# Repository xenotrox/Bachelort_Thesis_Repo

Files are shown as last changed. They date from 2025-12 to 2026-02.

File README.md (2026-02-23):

# Real-Time sEMG Control of a Bionic Hand (Bachelor Thesis)

This repository contains the complete hardware, firmware, and software implementation for a surface Electromyography (sEMG) controlled bionic hand. The project serves as a functioning prototype developed for a Bachelor Thesis, focusing on real-time signal processing, feature extraction, and motor control.

The physical hand is based on a remixed version of the open-source **InMoov** robotic hand, optimized for reliability and educational demonstration.

## 📂 Repository Structure

The project is divided into four main directories, each containing its own specific documentation:

- **`/doc`**: Contains the final academic thesis (`Bachelorarbeit-1.pdf`) and the presentation slides used for the defense.
- **`/firmware`**: Contains the C++ code for the microcontroller (Arduino). It handles the real-time acquisition of analog sEMG signals (sampled at 1000 Hz), applies digital Butterworth bandpass filters, calculates muscle activation thresholds (Waveform Length), and actuates the servos safely.
- **`/hardware`**: Contains all 3D printing files (STLs and CAD). This includes the original and remixed InMoov hand parts (reinforced forearm with 5 mm bolt holes, upgraded servo pulleys, teflon tube guides) as well as the custom-designed display stand and electronics housing.
- **`/software`**: Contains the data science and analysis pipeline. Includes Jupyter Notebooks and Python modules used for evaluating raw signal noise, comparing filter performances (4th vs. 6th-order), extracting features, and training the activation thresholds used by the firmware.

## 🚀 Getting Started

To replicate or understand this project, it is recommended to explore the sub-modules in the following order:

1. **Hardware Assembly**: See `/hardware` to print the PLA components and assemble the tendon-driven hand.
2. **Data Analysis**: Navigate to `/software` to see how raw sEMG signals were analyzed and how the filter coefficients and muscle activation thresholds were calculated.
3. **Microcontroller Setup**: Go to `/firmware` to flash the main control code onto the Arduino and start reading real-time muscle inputs.

## 🛠️ Key Technologies & Requirements
- **Microcontroller:** Arduino Uno (or compatible)
- **Programming Languages:** C++ (Firmware), Python 3.x (Software Analysis)
- **Data Analysis Libraries:** `numpy`, `pandas`, `scipy`, `matplotlib`, `jupyter`
- **3D Printing:** FDM Printer, PLA Filament

## 📜 Credits
The physical hand design is heavily based on the [InMoov open-source 3D printable robot](https://inmoov.fr/) created by Gael Langevin, utilizing remixes specifically tailored for improved tendon tension and forearm strength.

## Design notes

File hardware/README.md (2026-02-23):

# Hardware

This directory contains all the 3D models and CAD files needed to physically build the bionic hand and its display stand.

## Structure
- **InMoov/**: Contains the files for the robotic hand.
  - **Original/**: Unmodified STL files directly from the open-source InMoov project (Fingers, Forearm, RightHand, RotationWrist).
  - **Remix/**: Modified parts customized for this project, including a reinforced forearm with 5 mm bolt holes and updated servo pulleys for the tendon system.
- **Custom Stand/**: Original CAD designs for the educational display stand, including the Arduino holder, bottom box and top box.
- **Printer Calibration/**: Small test STLs used to dial in the 3D printer's Z-offset and dimensional accuracy before printing the final parts.

## Printing Notes
All parts are designed to be printed in PLA. Please refer to the specific README files in the subdirectories (e.g., `InMoov/Remix/Forearm/README.txt`) for specific infill and speed recommendations.

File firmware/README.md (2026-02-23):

# Firmware

This directory contains all Arduino C++ code and related scripts required to operate the bionic hand prototype. 

## Structure
- **Hand_Control/**: The main production code for the Arduino Uno. It processes analog sEMG signals using a 6th-order Butterworth bandpass filter, calculates the Waveform Length (WL), and actuates the servo motors based on trained thresholds. It also includes `serial_plotter.py` for real-time visualization on a connected PC.
- **tests/**: A collection of isolated Arduino sketches used during development to verify individual components. Includes tests for LEDs, potentiometers, servo limits (`Hand_Test`), filter performance, and sensor connectivity.

## Setup
Upload the `Hand_Control.ino` sketch to your Arduino Uno using the Arduino IDE. Ensure the custom C++ filter libraries (`BandpassFilter6thOrder.h`/`.cpp`) are in the same directory.

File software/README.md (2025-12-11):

# Analysis & Control Software

This directory contains the Python code and Jupyter Notebooks used for processing sEMG signals, training threshold models, and evaluating filter performance for the Bachelor Thesis.

## 📦 Prerequisites

This project requires **Python 3.x** and the following scientific libraries. You can install them via pip:

```bash
pip install numpy pandas scipy matplotlib jupyter
```
Note: If you wish to generate production-ready plots with LaTeX formatting, ensure you have a local LaTeX distribution installed (e.g., TeX Live or MiKTeX) and set ENABLE_LATEX = True in src/config.py.

## 📂 Directory Structure

- notebooks/: The main entry points for analysis. These are numbered to indicate the recommended execution order.
- src/: Helper modules containing the core logic (filters, feature calculation, data loading).
  - config.py: Global settings (sampling rate, constants, plotting options).
  - filters.py: Implementation of Notch and Butterworth filters.
  - features.py: Signal feature extractors (RMS, Variance, Waveform Length).
  - data_loader.py: Utilities for loading raw ADC text files and labeled CSVs.
- data/: Place your raw signal files (.txt) and labeled training data (.csv) here.
- results/: Generated plots, trained threshold values, and filter coefficients are saved here automatically.

## 🚀 Usage Guide

It is recommended to run the notebooks in the following order to replicate the full analysis pipeline:
### 1. Raw Signal Analysis

- File: 01_Raw_Signal_Analysis.ipynb
- Goal: Visual inspection of the raw sEMG signal directly from the ADC.
- Key Output: Plots showing the DC offset (approx. 1.5V) and baseline noise.

### 2. Filter Evaluation

- File: 02_Filter_Evaluation.ipynb
- Goal: Compare the "Original Filter" (Notch + Simple High/Low pass) against 4th and 6th Order Butterworth designs.
- Key Output: Power Spectral Density (PSD) plots and signal-to-noise comparisons to justify the final filter choice.

### 3. Model Training

- File: 03_Model_Training_Evaluation.ipynb
- Goal: Load labeled training sequences to determine optimal thresholds for muscle activation.
- Key Output: Generates trained_thresholds.csv in the results folder.

### 4. Feature Evaluation

- File: 04_Feature_Evaluation.ipynb
- Goal: Compare different feature extraction methods (RMS vs. Variance vs. Waveform Length) for responsiveness and stability.

### 5. Real-Time Control Simulation

- File: 05_RealTime_Control.ipynb
- Goal: Simulates the final control logic using the selected filter and trained thresholds on test data.
    
## ⚙️ Configuration

You can adjust global settings in src/config.py:
- SAVE_PLOTS: Set to True to save figures to results/drafts or results/figures.
- ENABLE_LATEX: Set to True to use LaTeX fonts for plots (requires LaTeX installation).
- FS: Sampling frequency (Default: 1000 Hz).
- V_REF: ADC Reference Voltage (Default: 5.0 V).

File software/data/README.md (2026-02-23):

# Software Data

This directory stores the raw and processed datasets used by the Jupyter notebooks.

- **raw_signal.txt / realtime_stream.txt**: Unprocessed ADC serial dumps directly from the Arduino.
- **labeled_training_data/**: Contains sequence CSVs (`train_seq_01.csv` to `train_seq_10.csv`) used to train the activation threshold models. These files include the filtered signal and a binary label indicating muscle contraction.
- **test_data/**: Contains diverse validation sets (e.g., fatigue tests, sudden dropouts, quick pulses) to evaluate the system's robustness in real-world scenarios.

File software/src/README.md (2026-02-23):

# Source Code (src)

This directory contains the core Python modules used by the Jupyter Notebooks for analysis.

- **config.py**: Global configuration variables (e.g., 1000 Hz sampling rate, ADC voltage, plotting preferences).
- **data_loader.py**: Functions to parse raw `.txt` serial logs and labeled `.csv` training data into Pandas DataFrames.
- **features.py**: Implementations of feature extraction algorithms (Waveform Length, Root Mean Square, Variance).
- **filters.py**: Signal processing functions, including Notch filters for powerline noise and digital Butterworth bandpass filters.
- **visualization.py**: Helper functions for generating standardized matplotlib graphs.

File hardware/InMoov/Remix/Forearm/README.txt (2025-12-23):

Inmoov Forearms Modded by Mindless on Thingiverse: https://www.thingiverse.com/thing:1927150

Summary:
Many Thanks to -Mr Gael- "Inmoov" DesignerForearm’s- Part-A -Part-B-“ Plus” Upper and Lower WristThis Mod joins the Four smaller sections into Two-,, the forearms total height is just under 200mm high,,, so make sure you can print this high before starting !!,I have included the small section pieces if you can’t print that high, the bolthole has been reduced to 5mm to increase strength- the pictures give you all the information youneed there is no change to the actual design except for the 5mm bolt hole, and 2.2mm extension toreduce the angle and add a bit more strength,, all pieces where hand joined and are error free-the Bicep servo mount has been modded to have a 5mm hole to match the forearms- Slow down the printing speed due the small Footprint and because how tall it is, but also because itIs a thin object the infill will have short rapid movement this will make the object become unstuck ifthey became too violent so set infill speed to- 60mm/sec- and tick the box that allows-“collapse thin lines into single trace  which is “on”  by default in Sli3er,- there’s a good chance you will get the “Death Shakes” if  this is turned off and the infill speed is higher than 60mm/sec-  there is a speed setting in Slic3r that is meant to deal with this problem but it’s a “Hit or Miss” when an object is sliced up- I’ve learnt not to Trust it…My Forearms where printed using PLA- ED3v6-- 0.4mm NozzleLayer Hight -0.3mmLayer Default Width-0.5Perimeters -2 - both@ 40mm/sec-Infill- 100% @ 60mm/secBrim- 15 Loops- 3-Layers highReducing the printing speed on some object makes only a small difference on printing time, same as using 100% infill- it will only use a few extra meters of filament- this is one of them Objects, it’s worth taking the time to do right-The" Upper" and" Lower"- Wrists (pic-9) have had the walls thickened In certain sections due to bleeding in the walls at some spots (Horizontal Scarring ) this was probably a result of my printing setting and not a fault of the part- but the part is a lot stronger now and still compatible with everything else,,,Parts fit together beautifully and very little clean-up is requiredif you your printing the x4 Short pieces with the 5mm Elbow holes you have to go to the inmoov website to get the -Top Sections- all the parts are backwards Compatible--SketchUp Files are included with the Download for you to mod --=Mindless=-*Note- 2--One picture shows all the Mods available in my collection but only the Forearms are includedin this download

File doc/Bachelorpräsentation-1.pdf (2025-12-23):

# Real-Time sEMG Control of a Bionic Hand for Educational Demonstration

## Lukas Zach

Bachelor Thesis Presentation TU Graz, Institute of Biomedical Imaging 01.12.2025

# Motivation ²

Introduction

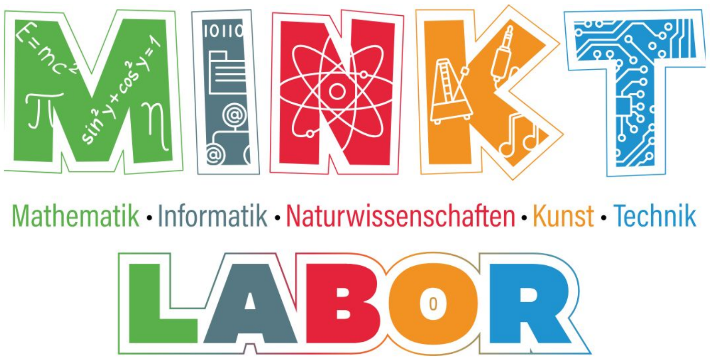
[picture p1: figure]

Image: Super Science Team, TU Graz

# Motivation ²

Introduction

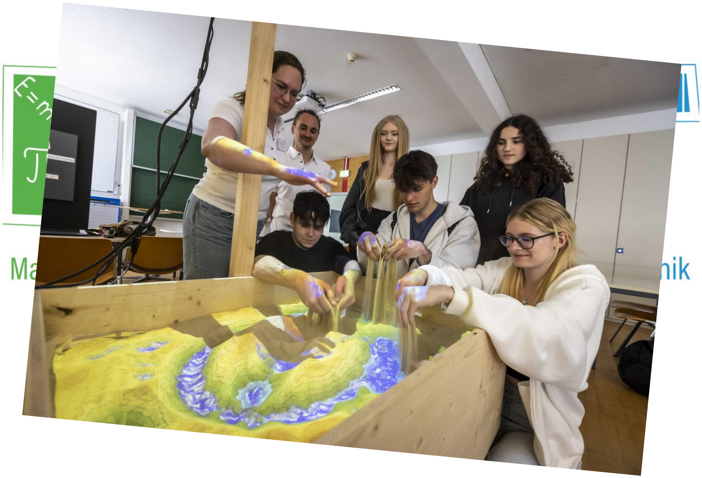
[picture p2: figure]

Image: Super Science Team, TU Graz

# Motivation ²

Introduction

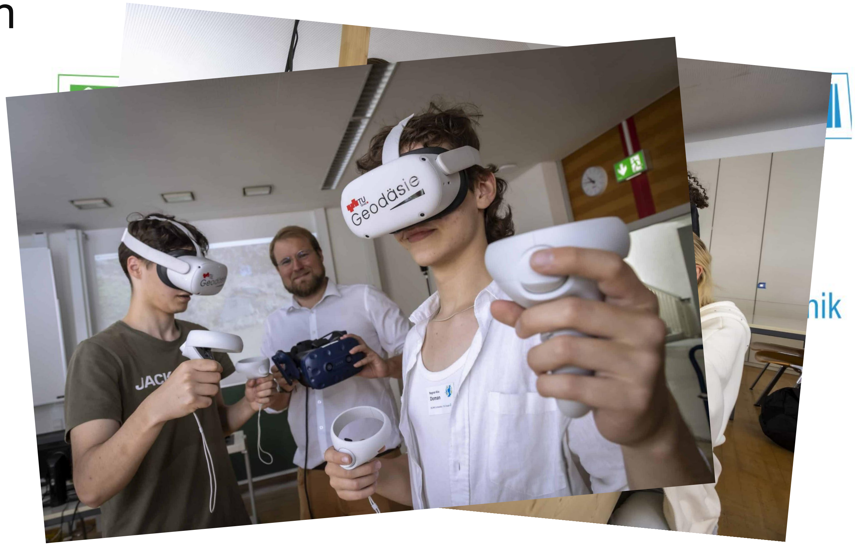
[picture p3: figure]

Image: Lunghammer, TU Graz

# Motivation ²

Introduction

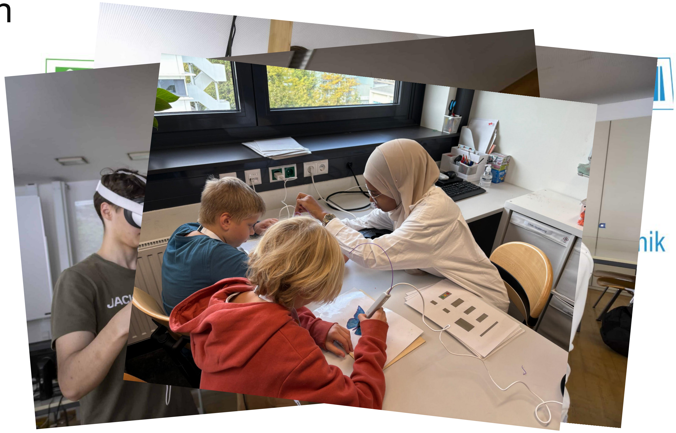
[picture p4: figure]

Image: Nina Botthof, TU Graz

# Motivation ²

Introduction

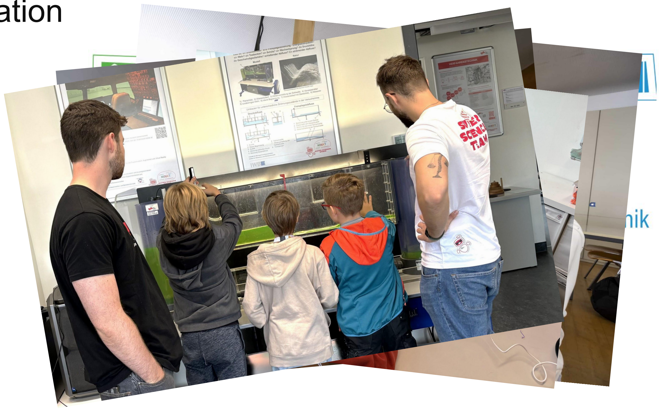
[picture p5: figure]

Image: Nina Botthof, TU Graz

# Motivation ²

Introduction

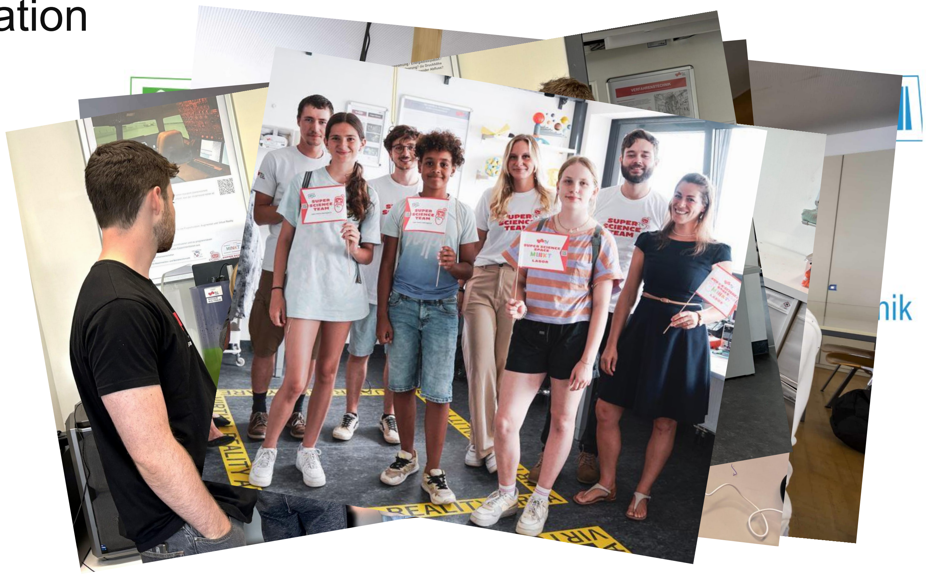
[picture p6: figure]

Image: Science Garden

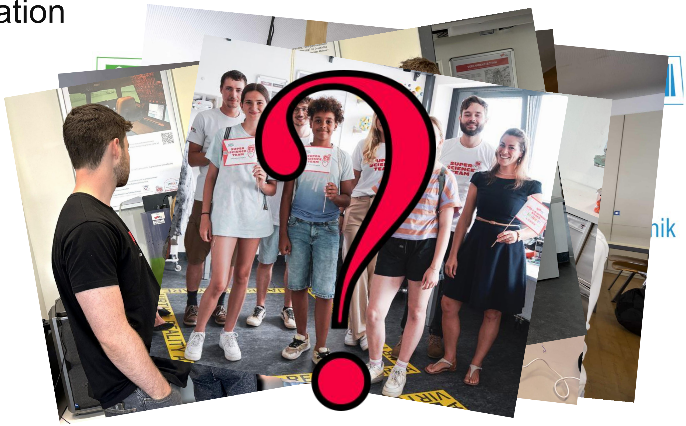
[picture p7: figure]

# Motivation ²

Introduction

# Goal ³

Introduction

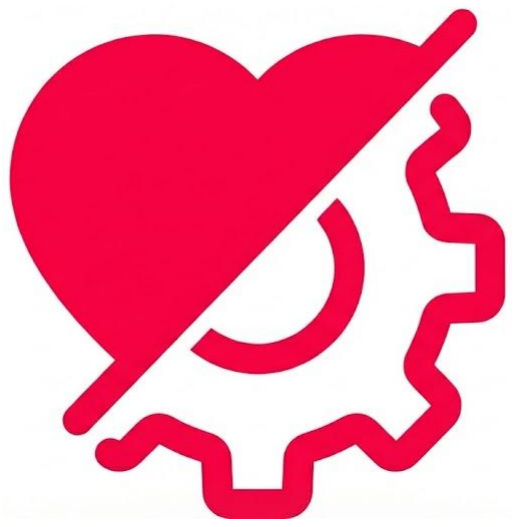
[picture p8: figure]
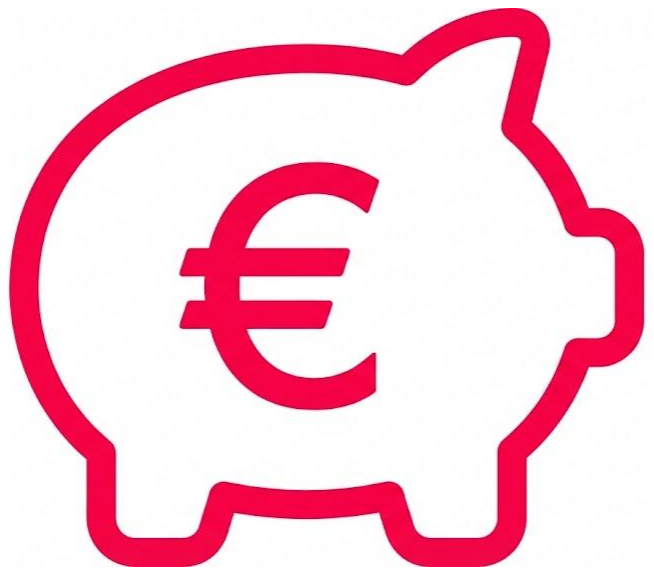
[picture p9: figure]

# Low budget

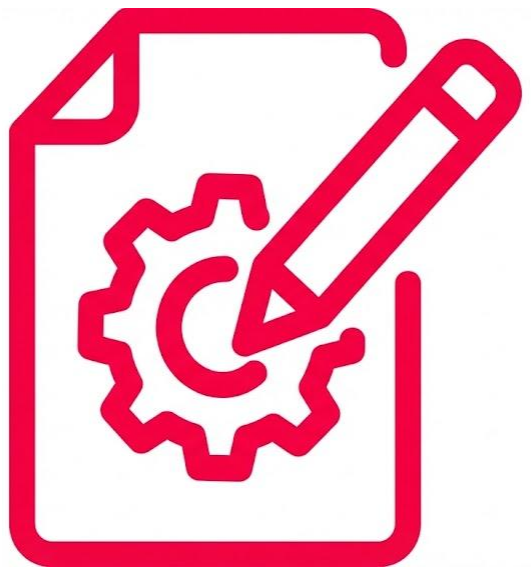
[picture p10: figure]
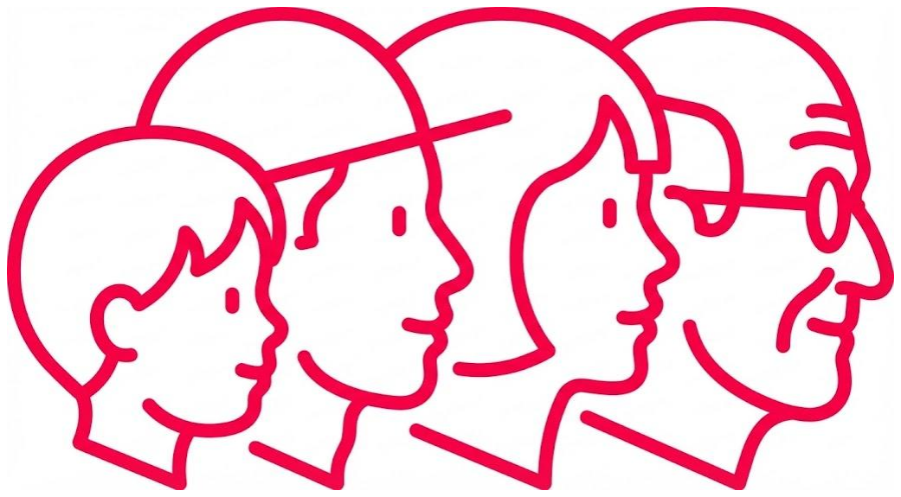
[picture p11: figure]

# Functioning Prototype

# Representative

# For all age Groups

Method

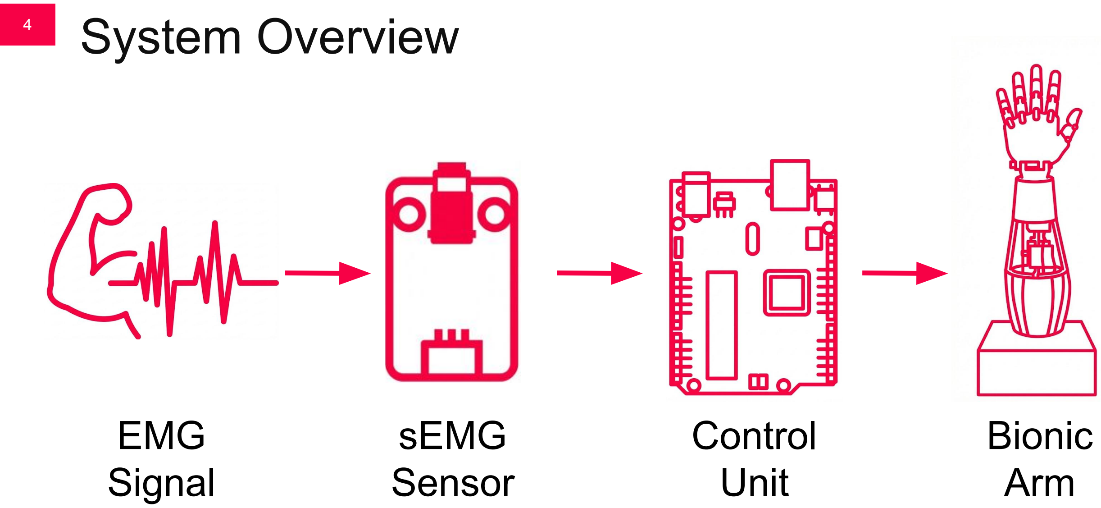
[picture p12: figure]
System Overview ⁴; EMG Signal; sEMG Sensor; Control Unit; Bionic Arm

# sEMG Signal ⁵

Method

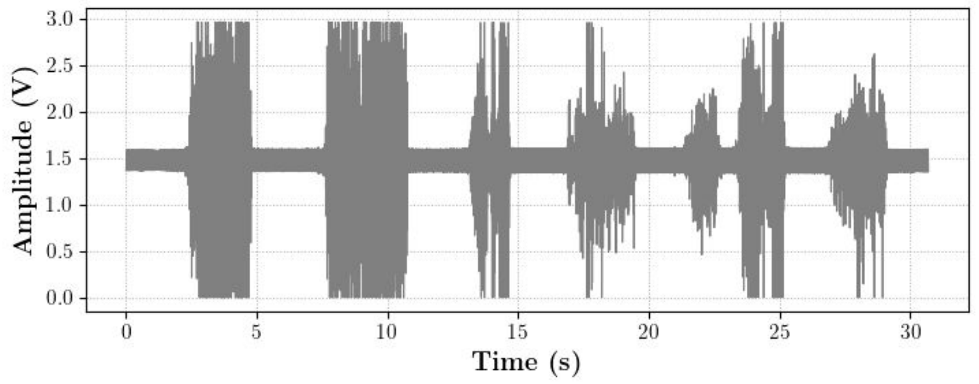
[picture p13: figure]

Image: Lukas Zach

# Gravity: Analog sEMG Sensor ⁶

Method

- Type: Dry Electrode Sensor.

## - Why: No conductive gel required (ideal

for high-traffic lab use).

## - Configuration: Differential amplification

(rejects common noise).

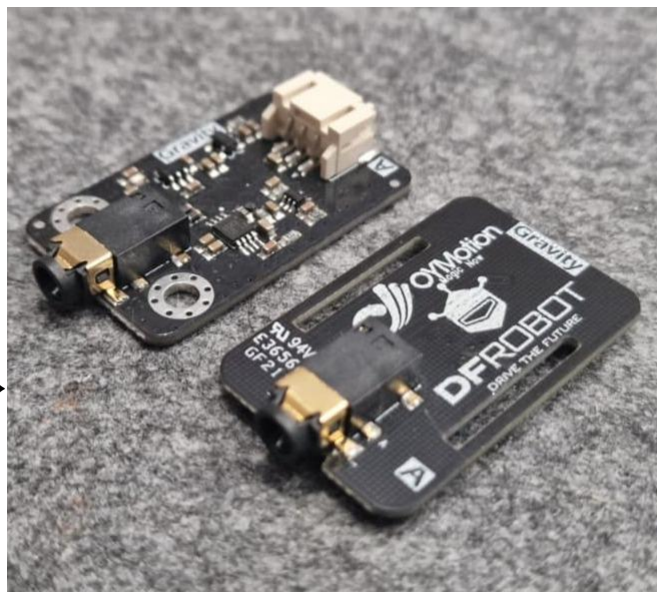
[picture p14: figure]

## - Output: Amplified analog signal (0–3V) →

Read by Arduino.

Image: Lukas Zach

# Control Unit ⁷

Method

### - Processor: Arduino Uno Rev3 (Sampling at

1000 Hz).

### - Interface: Sensor Shield V5.0 for easy

component connection.
- Power Logic: Isolated Power Supply.
- Arduino powered via USB.
- Servos powered by external 15A supply.

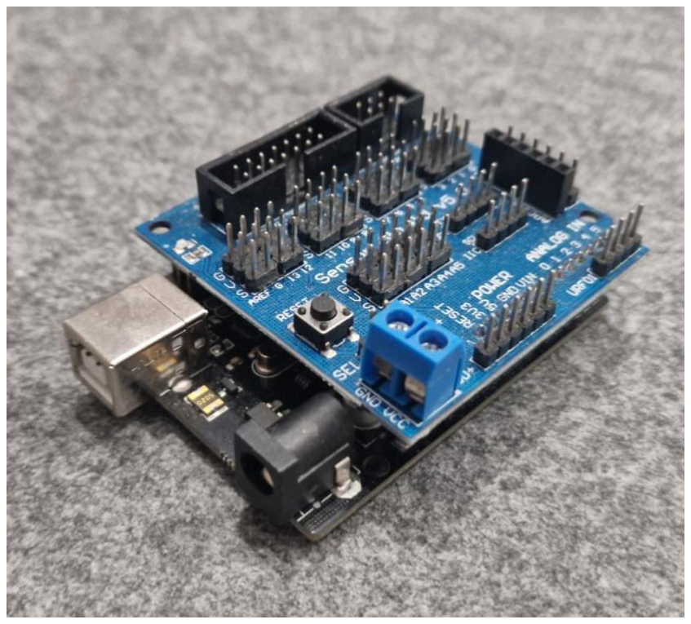
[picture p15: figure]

Image: Lukas Zach

# InMoov Bionic Arm ⁸

Method

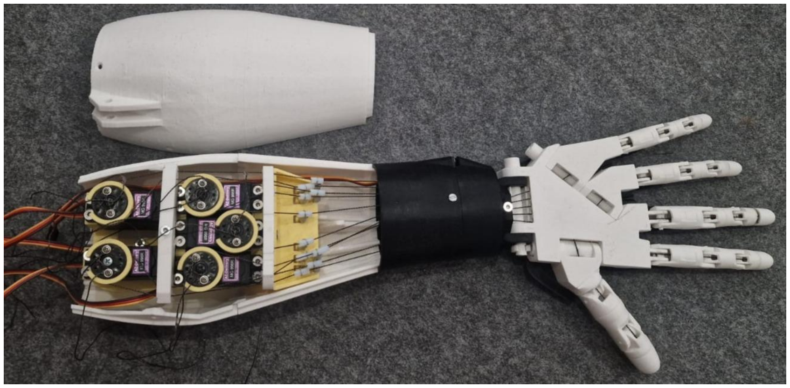
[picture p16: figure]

Image: Lukas Zach

# Mechanical Implementation ⁹

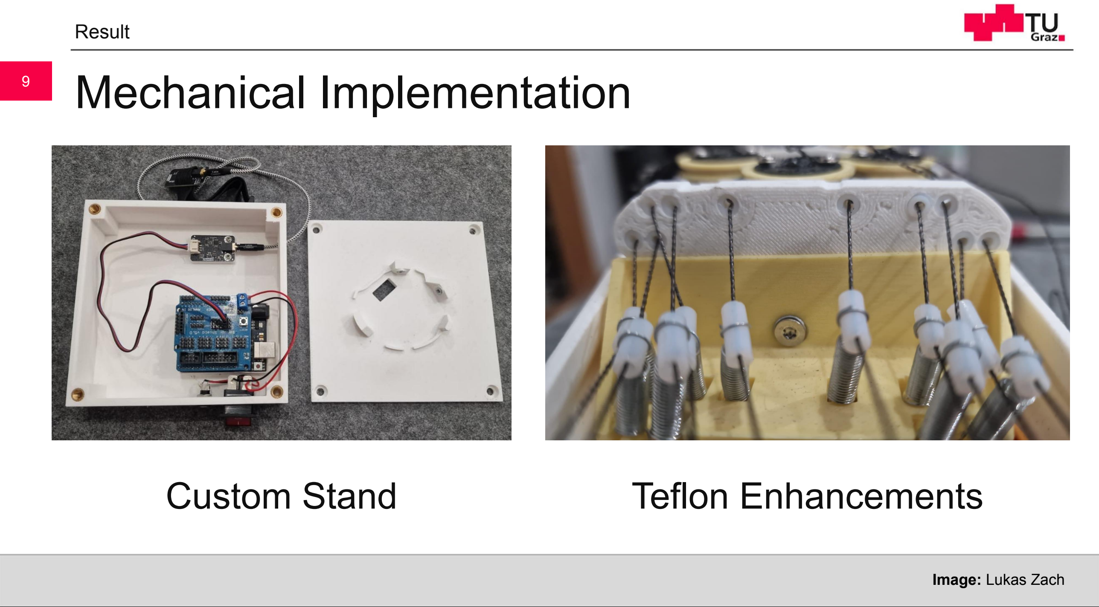
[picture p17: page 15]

Result

Custom Stand | Teflon Enhancements

Image: Lukas Zach

# Signal Processing: Filter Design ¹⁰

Result

Image: Lukas Zach

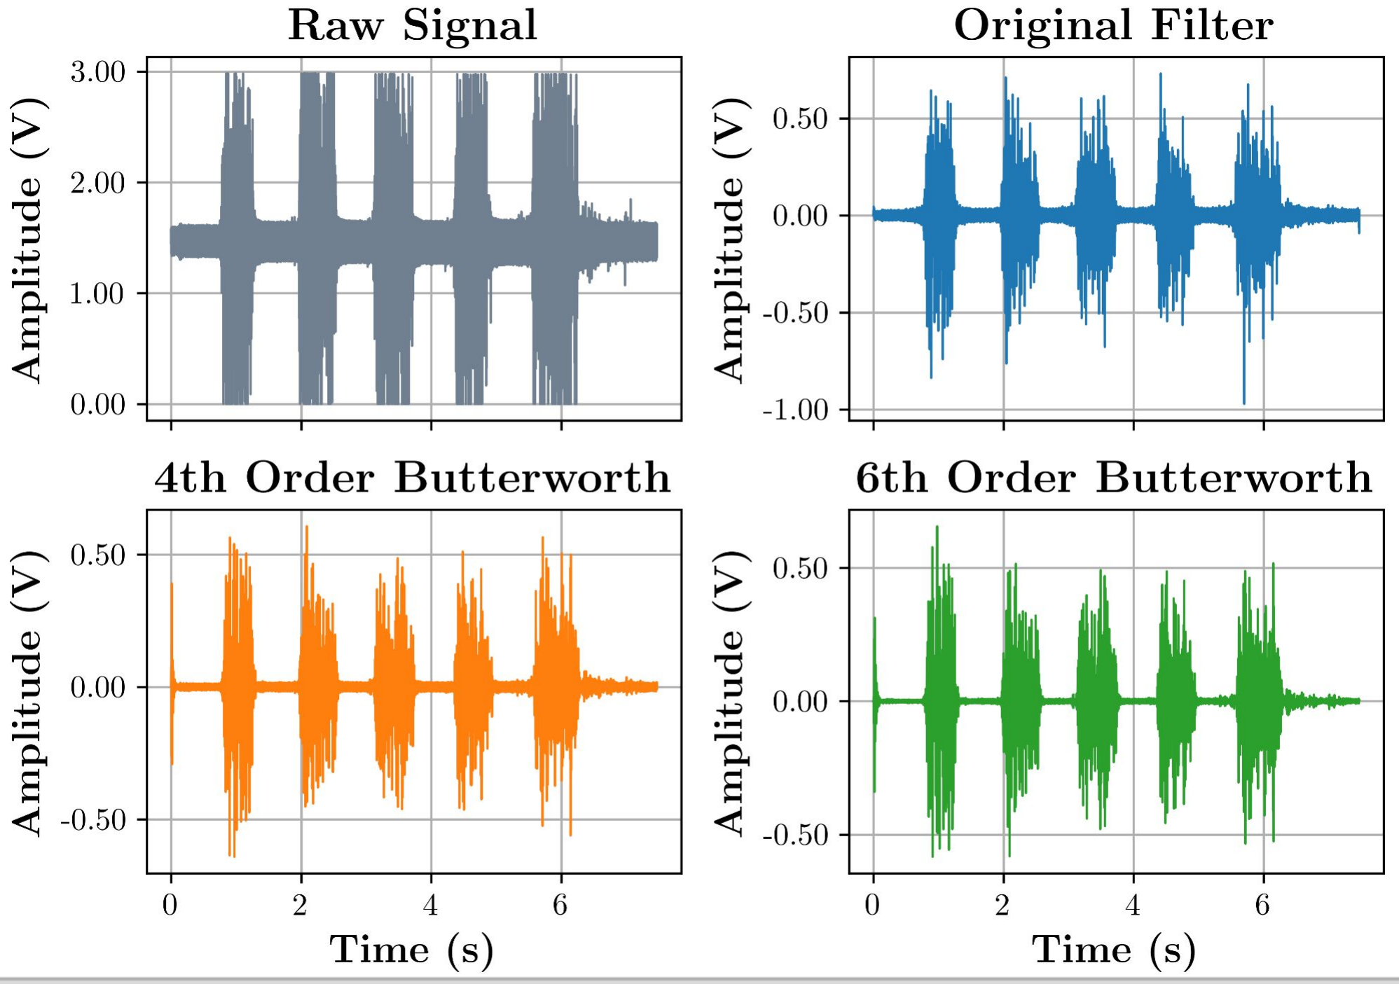
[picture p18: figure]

# Signal Processing: Filter Design ¹¹

Result

Image: Lukas Zach

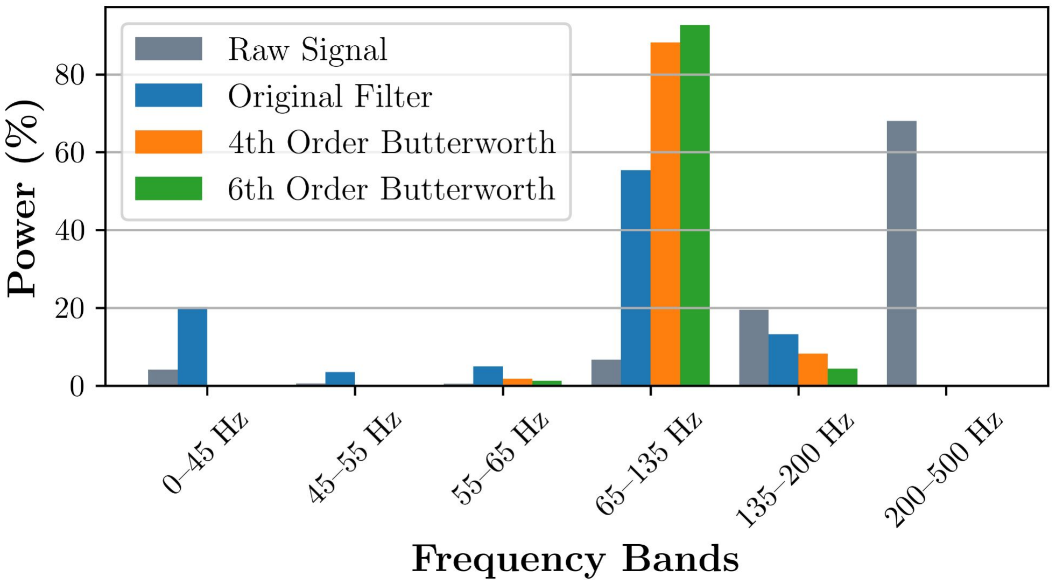
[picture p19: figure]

# Signal Processing: Feature Extraction ¹²

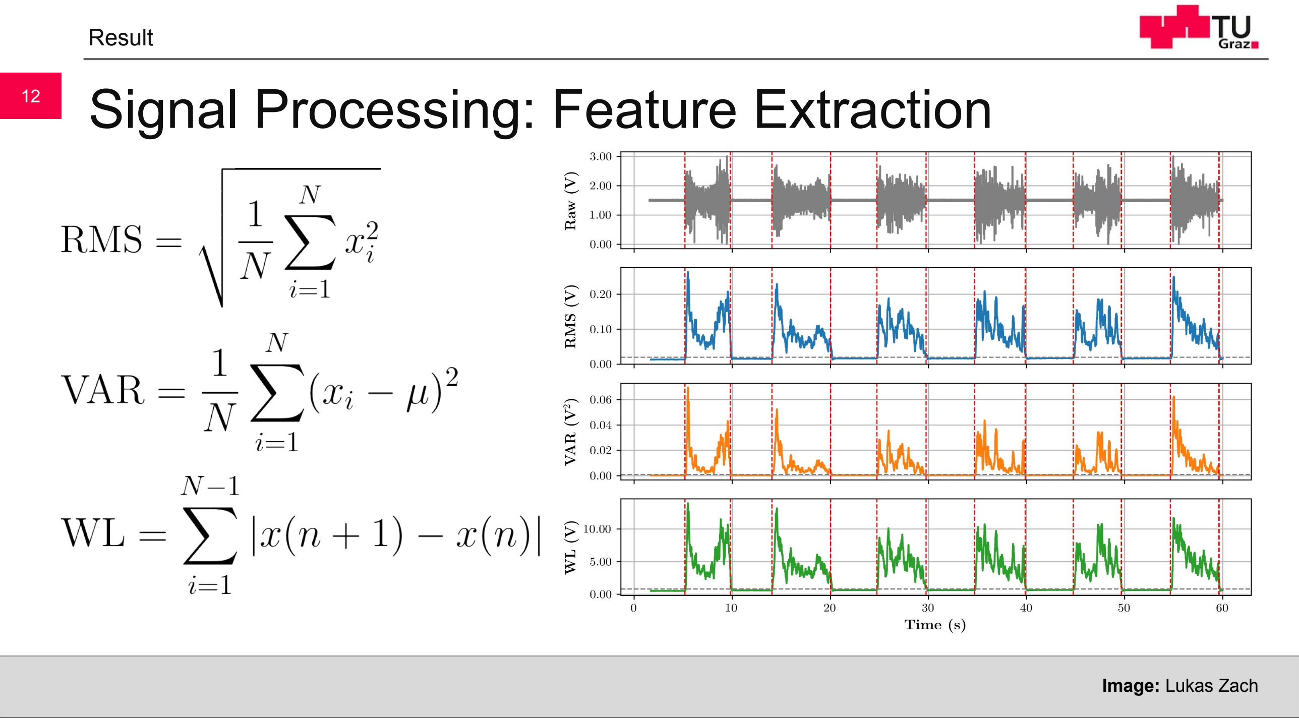
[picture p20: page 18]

Result

Image: Lukas Zach

# Signal Processing: Accuracy & Delay ¹³

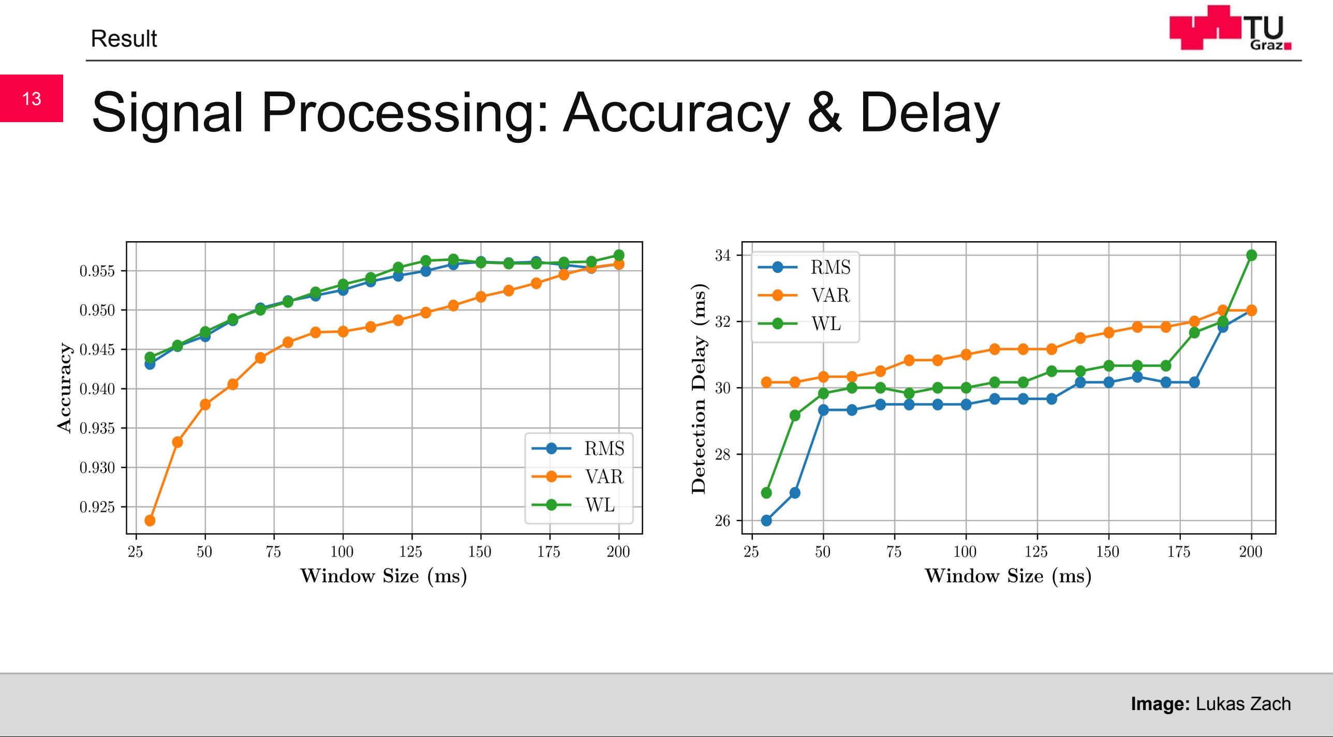
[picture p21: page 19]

Result

Image: Lukas Zach

# Discussion & Limitations ¹⁴

Result

## Signal Stability

- Issue: Sensor detachment creates massive noise
spikes.
- Impact: False positives
(unintended closing).
- Status: Software "Guard" added, but hardware
connection needs
improvement.

## Mechanical Wear

- Issue: Tendons (fishing line) stretch over time.
- Impact: Incomplete finger extension.
- Status: Teflon tubes
reduced friction, but regular re-tensioning is still
required.

## Usability & Scope

- Issue: Manual threshold
turning needed per user.
- Impact: Validated on N=4 subjects.
- Status: Auto-calibration required for unsupervised
public use.

# Conclusion ¹⁵

Result

# Achievements

✔ Functional Prototype:

Successfully integrated InMoov hand with custom sEMG control.

✔ Safety First:

Implemented dual-threshold "Disconnection Guard" to prevent erratic movement.

✔ Cost-Effective:

Created a repairable, modular system suitable for the MINKT Lab.

# Futur Work

→ Auto-Calibration:

Find a algorithm to adjust the thresholds automatically.

→ Long-Term Durability:

Conduct longer stress tests on the system and improve the tensioning system.

→ Hybrid Features:

Investigate combining RMS and Waveform Length or other features.

Image: Icons generated using Google Gemini.

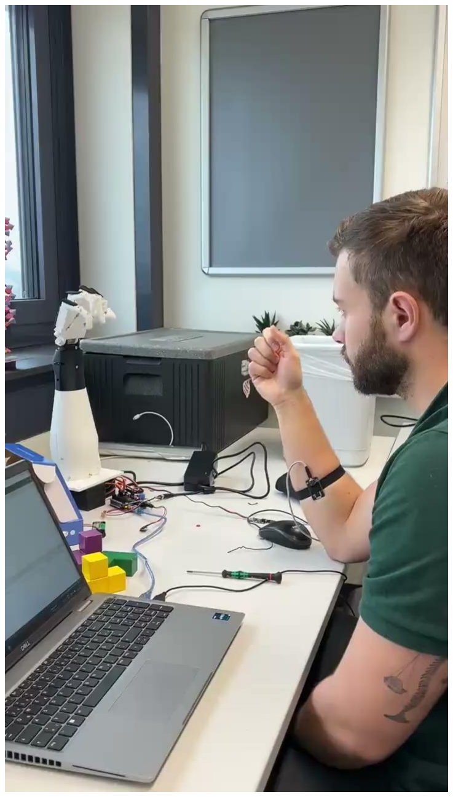
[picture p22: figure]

# Conclusion ¹⁵

Result

# Futur Work

→ Auto-Calibration:

Find a algorithm to adjust the thresholds automatically.

→ Long-Term Durability:

Conduct longer stress tests on the system and improve the tensioning system.

→ Hybrid Features:

Investigate combining RMS and Waveform Length or other features.

# Questions?

# Thank you for your attention!

## Lukas Zach

Bachelorprojekt
TU Graz, Institute of Biomedical Imaging 01.12.2025

# References

- TU Graz Super Science Team. (n.d.). TU Graz Super Science Space - MINKT Labor [Photograph]. Retrieved from https://super-science-team.tugraz.at/kurse/tu-graz-super-science-space-minkt-labor/
- TU Graz Super Science Team. (n.d.). Geoday 2023 [Photograph]. Retrieved from https://super-science-team.tugraz.at/geoday-2023/
- Lunghammer. (n.d.). Geoday 2023 [Photograph]. Retrieved from https://super-science-team.tugraz.at/geoday-2023/
- Nina Botthof. (n.d.). TU Graz Super Science Space - MINKT Labor [Photograph]. Retrieved from https://super-science-team.tugraz.at/open-your-mint/
- Science Garden. (n.d.). Super Science Space - MINKT Labor. Retrieved [Photograph], from https://www.sciencegarden.at/mint-erlebnis/super-science-space-minkt-labor-2/
- All icons used in this presentation were made using Google Gemini 3.

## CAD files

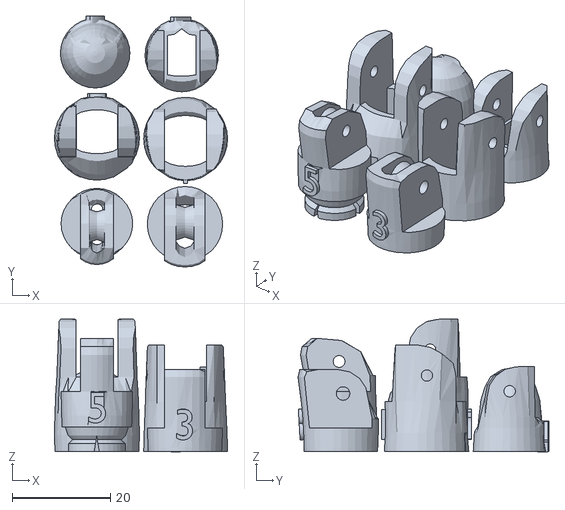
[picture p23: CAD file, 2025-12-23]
hardware/InMoov/Original/FingerStarterKit/FingerIndexV4.stl
35.3 x 51.2 x 27.1

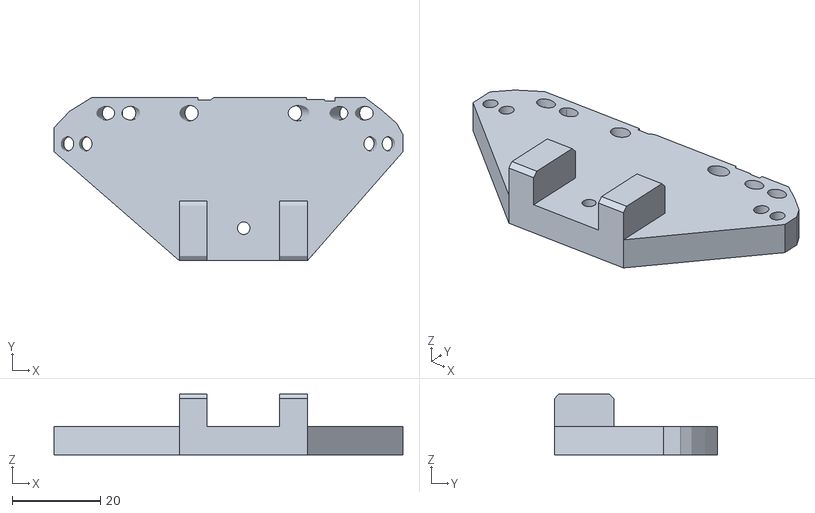
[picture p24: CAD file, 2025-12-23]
hardware/InMoov/Original/Forearm/RobCableFrontV3.stl
79.3 x 37.1 x 13.8

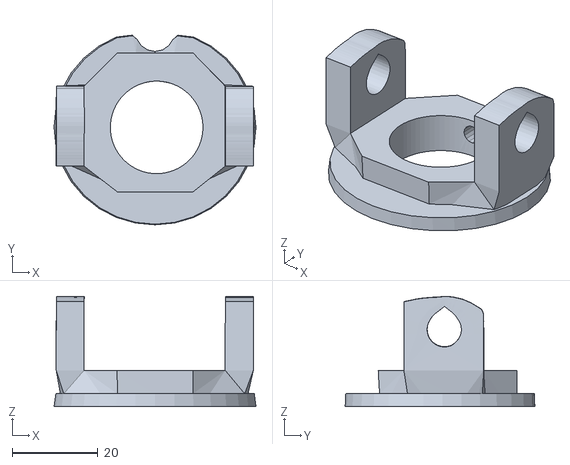
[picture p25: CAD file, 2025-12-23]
hardware/InMoov/Original/RotationWrist/RotaWrist3V3.stl
47.2 x 44.3 x 25.7

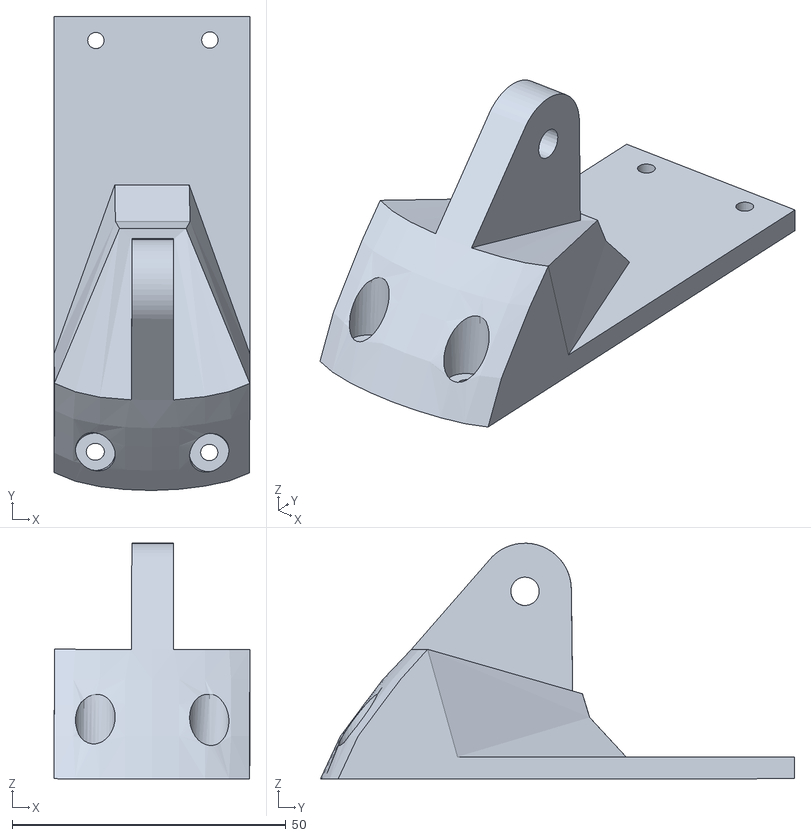
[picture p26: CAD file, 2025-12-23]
hardware/InMoov/Remix/Forearm/files/ServoMount_5mm.stl
35.8 x 86.6 x 43.1

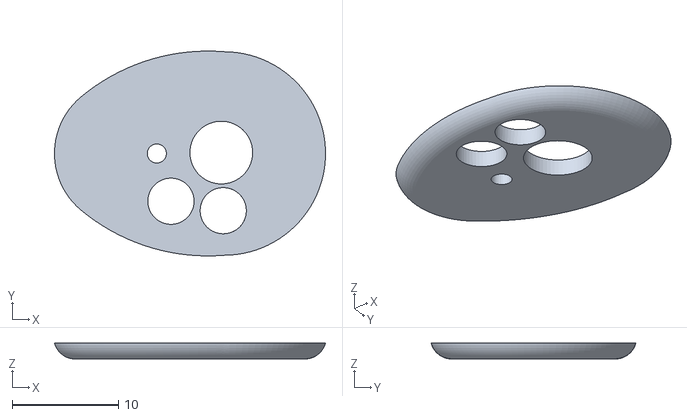
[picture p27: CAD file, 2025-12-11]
hardware/InMoov/Remix/Servo Pulley/Pulley_Top_V3.stl
25.5 x 19.3 x 1.50

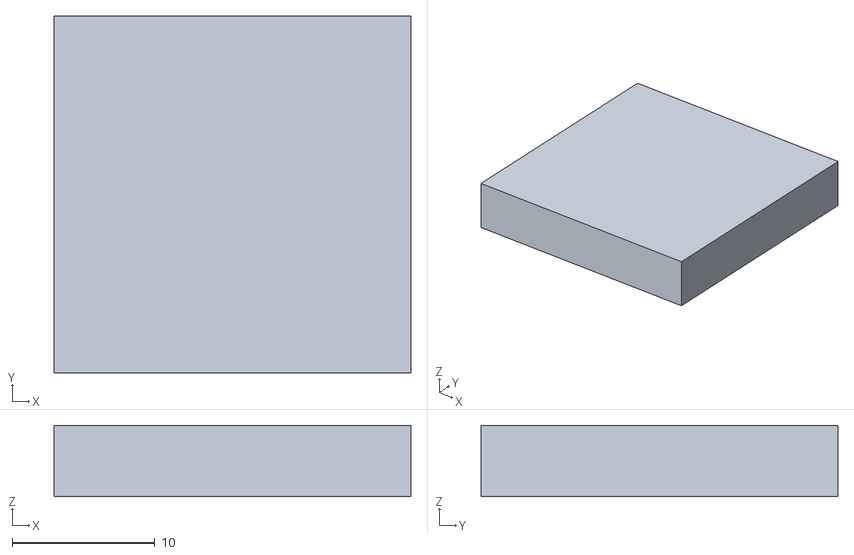
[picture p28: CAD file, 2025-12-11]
hardware/Printer Calibration/Z-Offest Test.stl
25.0 x 25.0 x 5.00

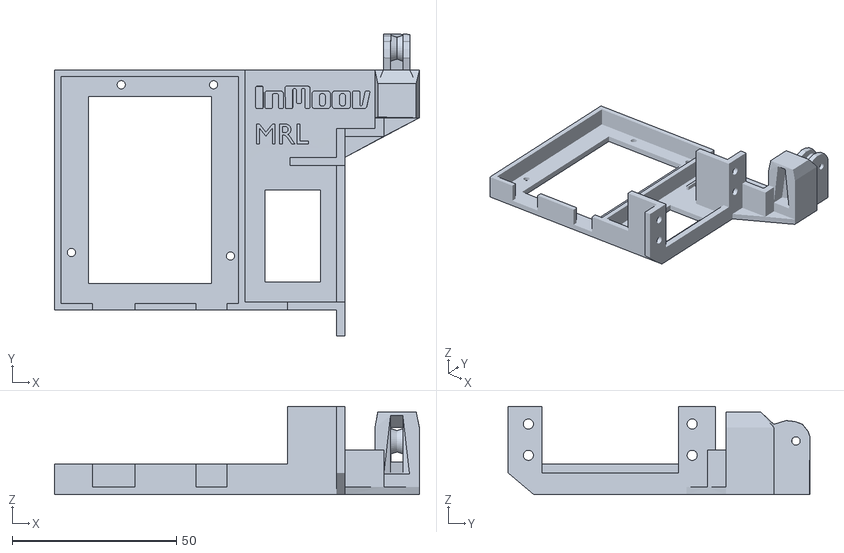
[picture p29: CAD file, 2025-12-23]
hardware/InMoov/Original/FingerStarterKit/FingerTesterV2.stl
111.0 x 91.8 x 26.9

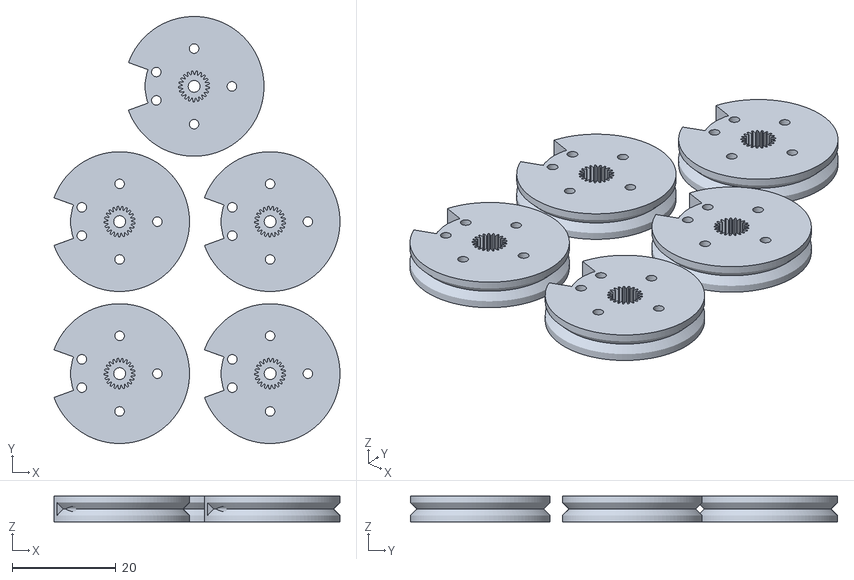
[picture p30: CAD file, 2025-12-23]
hardware/InMoov/Original/Forearm/RobRingV3.stl
55.3 x 82.5 x 5.00

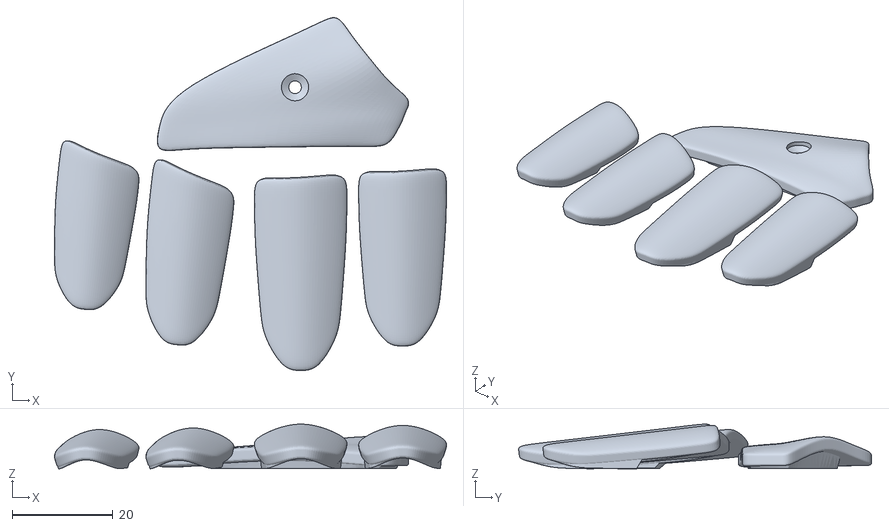
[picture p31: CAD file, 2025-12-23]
hardware/InMoov/Original/RightHand/coverfinger1.stl
77.7 x 69.9 x 8.87

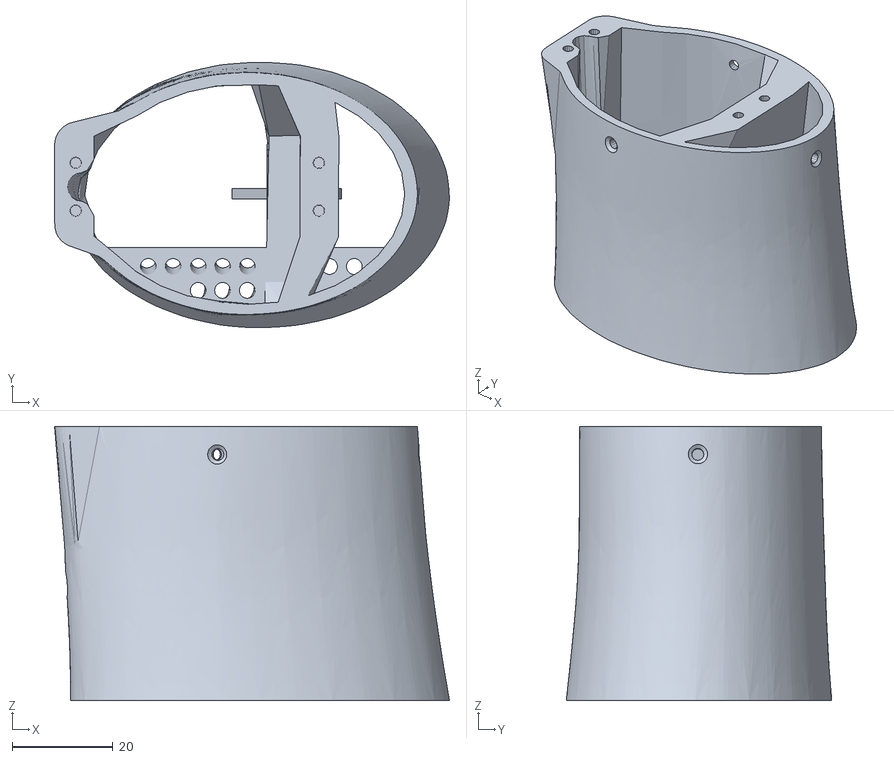
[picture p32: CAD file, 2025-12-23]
hardware/InMoov/Original/RotationWrist/RotaWrist1V4.stl
78.6 x 52.8 x 54.5

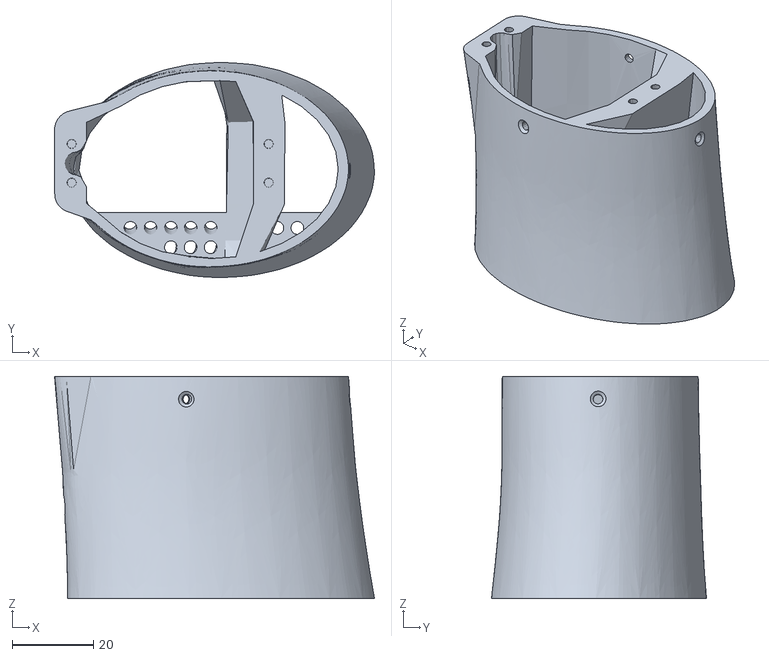
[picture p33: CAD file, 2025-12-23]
hardware/InMoov/Remix/Forearm/files/RH_Forearm_Part3.stl
78.6 x 52.8 x 54.5

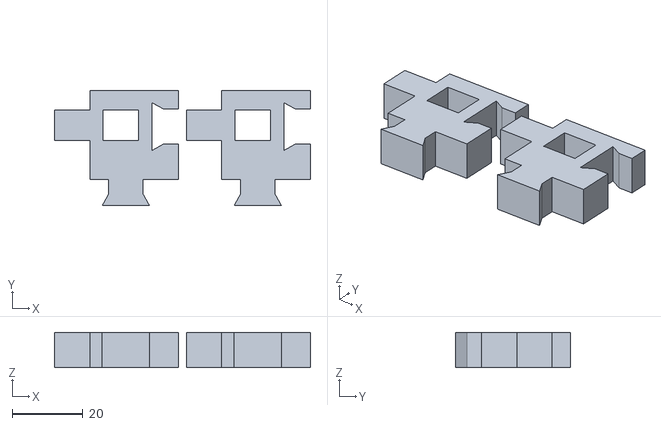
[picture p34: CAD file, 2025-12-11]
hardware/Printer Calibration/Calibrator.stl
72.2 x 32.5 x 9.99

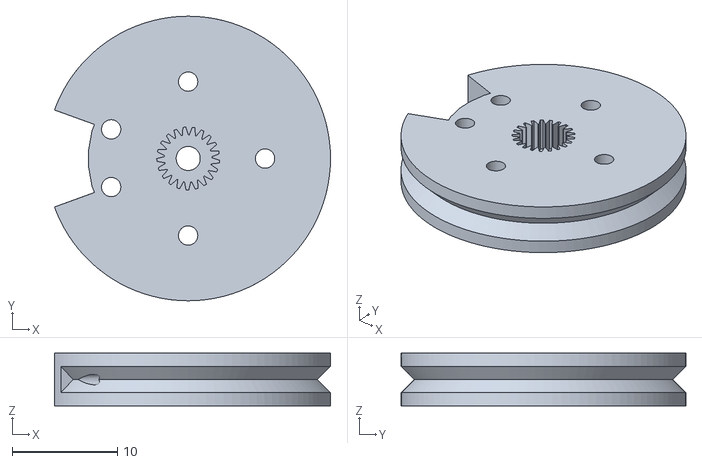
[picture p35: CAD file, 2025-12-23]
hardware/InMoov/Original/FingerStarterKit/RobRingV2.stl
26.2 x 27.0 x 5.00

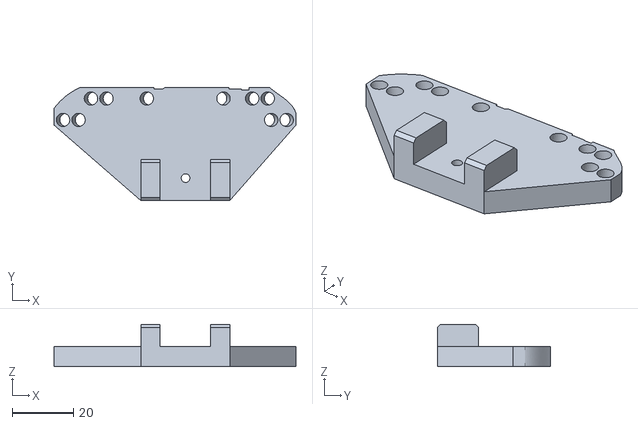
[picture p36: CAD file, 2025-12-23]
hardware/InMoov/Original/Forearm/RobCableFrontV3_TeflonTube.stl
79.3 x 37.1 x 13.8

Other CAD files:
hardware/InMoov/Original/RightHand/robcap3V2.stl
hardware/InMoov/Original/RotationWrist/CableHolderWristV5.stl
hardware/InMoov/Remix/Forearm/files/RH_Forearm_Part2.stl
hardware/InMoov/Original/FingerStarterKit/Servo-PulleyV2.stl
hardware/Custom Stand/Arduino_Holder.f3d
hardware/Custom Stand/BottomBox.f3z
hardware/Custom Stand/TopBox.f3d
hardware/InMoov/Original/Forearm/RobCableBackV3.stl
hardware/InMoov/Original/Forearm/RobCableFrontV3_TeflonTube.f3d
hardware/InMoov/Original/Forearm/RobServoBedV6.stl
hardware/InMoov/Original/Forearm/TensionerRightV1.stl
hardware/InMoov/Original/Forearm/Test_RotatedHole.stl
hardware/InMoov/Original/Forearm/servo-pulleyX5.stl
hardware/InMoov/Original/RightHand/Auriculaire3.stl
hardware/InMoov/Original/RightHand/Bolt_entretoise7.stl
hardware/InMoov/Original/RightHand/Index3.stl
hardware/InMoov/Original/RightHand/Majeure3.stl
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

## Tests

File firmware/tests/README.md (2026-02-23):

# Firmware Tests

This folder contains isolated Arduino sketches used for debugging and validating system components prior to integration into the main `Hand_Control` code.

- **Feature_Comparison/**: Compares calculation times for different signal features (RMS, Variance, WL).
- **Filter_Comparison/**: Tests 4th vs. 6th-order digital filters on the microcontroller.
- **Hand_Test/**: Actuates the InMoov servos to calibrate finger limits and tendon tension.
- **LED_Test / Potentiometer_Test**: Validates the user interface components.
- **Sensor_Connection**: Code to detect if the sEMG sensor has been physically disconnected from the user.
- **State_Machine / WL_Test**: Validates the core logic loop and Waveform Length math.

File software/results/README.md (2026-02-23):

# Results

This directory is the output destination for the Python analysis scripts.

- **drafts/**: Contains generated PNG plots (e.g., PSD comparisons, raw signal visualizations, feature accuracy graphs). 
- **filter_coeffs/**: Saved NumPy array files (`.npy`) containing the calculated A and B coefficients for the 4th and 6th-order digital Butterworth filters, ready to be hardcoded into the Arduino C++ firmware.
- **thresholds/**: The final output of the training models. `trained_thresholds.csv` contains the calculated parameters for determining muscle activation states.

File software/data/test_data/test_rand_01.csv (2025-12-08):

Time | RawValue | Label
0.0 | 296.89594937687673 | relax
0.001 | 296.2414776548064 | relax
0.002 | 293.39808094063267 | relax
0.003 | 295.3559578178886 | relax
0.004 | 291.95322858675263 | relax
0.005 | 289.14450499966904 | relax
0.006 | 284.8311152766421 | relax
0.007 | 283.1484088685765 | relax
0.008 | 284.5230446621538 | relax
0.009 | 286.9232305675447 | relax
0.01 | 286.96750982816627 | relax
0.011 | 285.49368814764057 | relax
0.012 | 286.9513166529225 | relax
0.013 | 287.05851980111464 | relax
0.014 | 294.45733966467657 | relax
0.015 | 289.05061432365846 | relax
0.016 | 296.32648003795066 | relax
0.017 | 294.9484747624972 | relax
0.018 | 299.8082830077742 | relax
0.019 | 295.01619380731194 | relax
0.02 | 291.4866933811514 | relax
0.021 | 293.27720087353663 | relax
0.022 | 292.06261339028435 | relax
0.023 | 285.9726904008661 | relax
0.024 | 288.02921407726404 | relax
0.025 | 287.6391793353151 | relax
0.026 | 285.724396888334 | relax
0.027 | 288.30105703423834 | relax
0.028 | 286.436158367536 | relax
0.029 | 289.1691393689955 | relax
0.03 | 289.2734508471277 | relax
0.031 | 295.8916087041316 | relax
0.032 | 291.27001523319336 | relax
0.033 | 296.81363243125554 | relax
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

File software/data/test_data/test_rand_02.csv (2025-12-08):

Time | RawValue | Label
0.0 | 318.20261284006807 | relax
0.001 | 324.79057799248983 | relax
0.002 | 322.01921908410054 | relax
0.003 | 323.0888062315711 | relax
0.004 | 323.34351877766034 | relax
0.005 | 317.997725860573 | relax
0.006 | 316.8816886005908 | relax
0.007 | 315.9594812768182 | relax
0.008 | 317.19474133090665 | relax
0.009 | 312.3158449777928 | relax
0.01 | 314.98721699066414 | relax
0.011 | 316.70627831263465 | relax
0.012 | 319.74984722350524 | relax
0.013 | 322.70226486825044 | relax
0.014 | 321.7156508647531 | relax
0.015 | 326.8509367282673 | relax
0.016 | 323.96539470788497 | relax
0.017 | 325.6741174395725 | relax
0.018 | 322.5595864874933 | relax
0.019 | 316.78008604638086 | relax
0.02 | 318.1304120402009 | relax
0.021 | 318.23652663571255 | relax
0.022 | 313.12310178906006 | relax
0.023 | 312.09929016355915 | relax
0.024 | 313.7912569671741 | relax
0.025 | 319.69552264082034 | relax
0.026 | 319.8919086242455 | relax
0.027 | 320.36571417702066 | relax
0.028 | 330.9128967809352 | relax
0.029 | 327.0397614621235 | relax
0.03 | 324.4058279172311 | relax
0.031 | 324.03995757840227 | relax
0.032 | 321.34118396744077 | relax
0.033 | 314.2094708964055 | relax
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

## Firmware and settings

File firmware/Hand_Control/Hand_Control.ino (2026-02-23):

/**
 * Prosthetic Hand Control Logic
 * Signal: EMG/Sensor -> 6th Order Bandpass -> Waveform Length -> Servo Control
 * Features: Automatic timeout safety and sensor disconnection detection.
 */

// Library Imports
#include "Arduino.h"
#include "BandpassFilter6thOrder.h"
#include "Servo.h"

// Set to 0 to disable Serial output and speed up the loop
const bool DEBUG_MODE = 1;

// Pin Definitions
const uint8_t SERVO_PINS[5] = {3, 4, 5, 6, 7}; // D3-D7 {Pinky, Ring, Middle, Index, Thumb}
const uint8_t LED_OUT_OF_RANGE_PIN  = 12;      // Visual alert for loop timing issues
const uint8_t POTENTIOMETER_PIN  = 14;         // Sensitivity adjustment dial (A0)
const uint8_t SENSOR_PIN         = 15;         // Main EMG/Sensor input (A1)

// Servo configuration: default resting positions
const int openAngles[5] = {100, 110, 120, 120, 93}; // Specific angles for "Relaxed" pose
bool handStatus = 0;                                // Current state: 0 for Open, 1 for Closed
Servo fingers[5];

// Timing & Signal Processing Math
const int SAMPLE_RATE = 1000;                              // Aiming for 1kHz sampling
const unsigned long SAMPLE_PERIOD = 1000000 / SAMPLE_RATE; // Period in microseconds (1000us)
const int WINDOW_SIZE = 90;                                // Number of samples used to calculate signal strength

// Thresholds for Muscle Activation
const float THRESHOLD_MIN = 200;  // Minimum floor for activation
const byte SENSITIVITY = 5;       // Noise margin for the potentiometer dial

// Safety: Sensor Disconnection Logic (Detects if wire is pulled or floating)
const int UPPER_DISCONNECTION_THRESHOLD = 600;
const int LOWER_DISCONNECTION_THRESHOLD = 0;
const int COUNTER_MAX = 2000;     
const int DISCONNECT_TOLERANCE = 90;

// Motor Protection: Prevent stall heat by limiting contraction duration
const unsigned long MAX_CONTRACT_TIME = 5000;   // Release hand after 5s of continuous grip
const unsigned long COOLDOWN_MS = 1000;         // Mandatory 1s rest after a timeout

// State machine variables
unsigned long contractionStartTime = 0;
unsigned long pauseStartTime = 0;
bool isTimedOut = false;              // True if we are in the mandatory rest period
bool isCurrentlyContracting = false;  // Tracks if the muscle is actively engaged

int disconnect_counter = DISCONNECT_TOLERANCE;
int thresholdOld = THRESHOLD_MIN;
bool lastDetection = false;

// Optimization variables for running sum calculation
float currentWL = 0.0;
float lastFilteredValue = 0.0;

// Filter coefficients (generated for 6th order signal cleaning)
float sosCoeffs6th[3][6] = {
  {0.0121, 0.0242, 0.0121, 1.0, -1.3501, 0.7201},
  {1.0, 0.0, -1.0, 1.0, -1.5002, 0.8105},
  {1.0, -2.0, 1.0, 1.0, -1.7503, 0.8902}
};

BandpassFilter6thOrder thesisFilter;

// Data structure for the sliding window
float buffer[WINDOW_SIZE];
int bufferIndex = 0;
bool bufferFilled = false;

void setup() {
  // Setup hardware pins
  for (int i = 0; i < 5; i++) {
    fingers[i].attach(SERVO_PINS[i]);
  }

  Serial.begin(115200);

  // Ready the filter and clear the data buffer
  thesisFilter.init(sosCoeffs6th);
  for(int i = 0; i < WINDOW_SIZE; i++) buffer[i] = 0.0f;

  pinMode(LED_OUT_OF_RANGE_PIN, OUTPUT);

  open_hand();
}


// Adds new difference and removes oldest from the total
void updateWaveformLength(float newFilteredValue) {
  float oldestValue = buffer[bufferIndex];
  int prevToIndex = (bufferIndex + 1) % WINDOW_SIZE;
  float valueBeforeOldest = buffer[prevToIndex];

  // Remove the contribution of the data point that is leaving the window
  if (bufferFilled) {
    currentWL -= abs(oldestValue - valueBeforeOldest);
  }

  // Add the contribution of the newest data point
  currentWL += abs(newFilteredValue - buffer[bufferIndex == 0 ? WINDOW_SIZE - 1 : bufferIndex - 1]);

  buffer[bufferIndex] = newFilteredValue;
  bufferIndex = (bufferIndex + 1) % WINDOW_SIZE;
  if (bufferIndex == 0) bufferFilled = true;
}

// Read the user-adjustable threshold poti
int getThreshold() {
  int currentRead = analogRead(POTENTIOMETER_PIN);
  int targetThreshold = map(currentRead, 0, 1023, THRESHOLD_MIN, 1000);

  // Small deadzone to prevent the threshold from flickering
  if (abs(targetThreshold - thresholdOld) >= SENSITIVITY) {
    thresholdOld = targetThreshold;
  } 
  return thresholdOld;
}

void loop() {
  unsigned long startTime = micros();

  // Data Acquisition
  int rawValue = analogRead(SENSOR_PIN);
  bool sensorDisconnected = updateSensorStatus(rawValue);
  float filteredValue = thesisFilter.update((float)rawValue);

  // Calculate WL
  updateWaveformLength(filteredValue);

  // Logic Execution (Only once the buffer is full)
  if (bufferFilled) {
    float wlValue = currentWL;
    int threshold = getThreshold();
    bool signalDetected = (wlValue >= threshold) && !sensorDisconnected;
    unsigned long now = millis();

    // -- State Machine: Manage Contraction & Safety Timers --
    
    if (isTimedOut) {
      // We are in a forced cooldown period
      if (now - pauseStartTime >= COOLDOWN_MS) {
        isTimedOut = false; // Cooldown finished, ready for next read
      }
      open_hand(); 
    } 
    else if (signalDetected) {
      // Muscle contraction is detected
      if (!isCurrentlyContracting) {
        contractionStartTime = now; // Start the 5-second stopwatch
        isCurrentlyContracting = true;
      }

      // If the user contracts for too long, force the hand open to protect motors
      if (now - contractionStartTime >= MAX_CONTRACT_TIME) {
        isTimedOut = true;
        pauseStartTime = now;
        isCurrentlyContracting = false;
        open_hand();
      } else {
        close_hand();
      }
    } 
    else {
      // No muscle contraction
      isCurrentlyContracting = false;
      open_hand();
    }

    if (DEBUG_MODE) {
      debug(rawValue, filteredValue, wlValue, threshold, signalDetected, sensorDisconnected,  isTimedOut);
    }   
  }

  // Ensures the loop runs at exactly the SAMPLE_RATE (1kHz)
  unsigned long elapsedTime = micros() - startTime;
  if (elapsedTime < SAMPLE_PERIOD) {
    delayMicroseconds(SAMPLE_PERIOD - elapsedTime);
  }
}

// Logic to detect if the sensor is likely disconnected based on extreme voltage readings
bool updateSensorStatus(int raw) {
  if (raw >= UPPER_DISCONNECTION_THRESHOLD || raw <= LOWER_DISCONNECTION_THRESHOLD) {
    disconnect_counter++;
  } else {
    disconnect_counter--;
  }

  disconnect_counter = constrain(disconnect_counter, 0, COUNTER_MAX);

  // Returns true if the sensor has been "out of bounds" for a sustained period
  return (disconnect_counter > DISCONNECT_TOLERANCE);
}

// Actuate motors to the open (resting) position
void open_hand() {
  if (handStatus) { // Only send command if we aren't already open
    for (int i = 0; i < 5; i++) {
      fingers[i].write(openAngles[i]);
    }
    handStatus = 0;
  }
}

// Actuate motors to the closed (grip) position
void close_hand() {
  if (!handStatus) { // Only send command if we aren't already closed
    for (int i = 0; i < 5; i++) {
      fingers[i].write(0);
    }
    handStatus = 1;
  }
}

// Standard CSV-formatted output for Serial Plotter
void debug(int rawValue, float filteredValue, float wlValue, int threshold, int detection, bool sensorDisconnected,bool timedOut) {
    Serial.print(",Raw:");          Serial.print(rawValue);           
    Serial.print(",Filtered:");     Serial.print(filteredValue);
    Serial.print(",WL:");           Serial.print(wlValue);            
    Serial.print(",Threshold:");    Serial.print(threshold);    
    Serial.print(",Detection:");    Serial.print(detection * 1000);
    Serial.print(",Disconnected:"); Serial.print(sensorDisconnected * 1000);
    Serial.print(",Counter:");      Serial.print(disconnect_counter);
    Serial.print(",TimedOut:");     Serial.println(timedOut * 1000);
}

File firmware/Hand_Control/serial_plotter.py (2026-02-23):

import serial
import threading
import time
import collections
import matplotlib.pyplot as plt
from matplotlib.animation import FuncAnimation

# --- Configuration ---
PORT = "COM3"
BAUD = 115200
WINDOW_SIZE = 10  # Seconds to show on the X-axis

# Deques for the scrolling graphs
times = collections.deque(maxlen=2000)
raw_data = collections.deque(maxlen=2000)
wl_data = collections.deque(maxlen=2000)
thresh_data = collections.deque(maxlen=2000)
counter_data = collections.deque(maxlen=2000)

# Dictionary for the instant LED status
current_status = {"Detection": 0.0, "Disconnected": 0.0, "TimedOut": 0.0}

is_running = True
start_time = time.time()


# ==========================================
# THREAD 1: Data Acquisition
# ==========================================
def read_serial_data():
    try:
        arduino = serial.Serial(port=PORT, baudrate=BAUD, timeout=0.1)
        time.sleep(2)
    except Exception as e:
        print(f"Error opening serial port: {e}")
        return

    while is_running:
        if arduino.in_waiting > 0:
            try:
                raw_line = arduino.readline().decode("utf-8").strip(", \r\n")
                if not raw_line:
                    continue

                data = {
                    k: float(v)
                    for pair in raw_line.split(",")
                    if ":" in pair
                    for k, v in [pair.split(":")]
                }

                # 1. Update LEDs directly
                if "Detection" in data:
                    current_status["Detection"] = data["Detection"]
                if "Disconnected" in data:
                    current_status["Disconnected"] = data["Disconnected"]
                if "TimedOut" in data:
                    current_status["TimedOut"] = data["TimedOut"]

                # 2. Update Graph History
                current_t = time.time() - start_time
                times.append(current_t)
                raw_data.append(data.get("Raw", 0))
                wl_data.append(data.get("WL", 0))
                thresh_data.append(data.get("Threshold", 0))
                counter_data.append(data.get("Counter", 0))

            except (ValueError, UnicodeDecodeError):
                pass

    arduino.close()


data_thread = threading.Thread(target=read_serial_data, daemon=True)
data_thread.start()

# ==========================================
# THREAD 2: Plot Rendering
# ==========================================
fig = plt.figure(figsize=(10, 9))
fig.canvas.manager.set_window_title("Arduino Hybrid Dashboard")

# Use GridSpec to customize the layout
gs = fig.add_gridspec(4, 1, height_ratios=[1, 2, 2, 2])

# Row 0: Status Lights (Independent Axes)
ax_lights = fig.add_subplot(gs[0, 0])
ax_lights.axis("off")
ax_lights.set_xlim(0, 1)
ax_lights.set_ylim(0, 1)

(light_det,) = ax_lights.plot(
    [0.2], [0.6], marker="o", markersize=35, color="lightgray"
)
ax_lights.text(0.2, 0.2, "Detection", ha="center", fontsize=12, fontweight="bold")

(light_disc,) = ax_lights.plot(
    [0.5], [0.6], marker="o", markersize=35, color="lightgray"
)
ax_lights.text(0.5, 0.2, "Disconnected", ha="center", fontsize=12, fontweight="bold")

(light_tout,) = ax_lights.plot(
    [0.8], [0.6], marker="o", markersize=35, color="lightgray"
)
ax_lights.text(0.8, 0.2, "Timed Out", ha="center", fontsize=12, fontweight="bold")

# Row 1: Raw Data
ax_raw = fig.add_subplot(gs[1, 0])
(line_raw,) = ax_raw.plot([], [], color="purple")
ax_raw.set_ylabel("Raw")
ax_raw.set_ylim(0, 615)
ax_raw.grid(True, linestyle=":", alpha=0.7)

# Row 2: WL and Threshold (Shares X with Raw)
ax_wl = fig.add_subplot(gs[2, 0], sharex=ax_raw)
(line_wl,) = ax_wl.plot([], [], label="WL", color="blue")
(line_thresh,) = ax_wl.plot([], [], label="Threshold", color="red", linestyle="--")
ax_wl.set_ylabel("WL / Thresh")
ax_wl.legend(loc="upper left")
ax_wl.grid(True, linestyle=":", alpha=0.7)

# Row 3: Counter (Shares X with Raw)
ax_counter = fig.add_subplot(gs[3, 0], sharex=ax_raw)
(line_counter,) = ax_counter.plot([], [], color="teal")
ax_counter.set_ylabel("Counter")
ax_counter.set_ylim(0, 2000)
ax_counter.set_xlabel("Time (seconds)")
ax_counter.grid(True, linestyle=":", alpha=0.7)


def update_dashboard(frame):
    # 1. Update Lights
    light_det.set_color(
        "#00FF00" if current_status["Detection"] >= 1000 else "lightgray"
    )
    light_disc.set_color(
        "#FF0000" if current_status["Disconnected"] >= 1000 else "lightgray"
    )
    light_tout.set_color(
        "#FFA500" if current_status["TimedOut"] >= 1000 else "lightgray"
    )

    if not times:
        return

    # 2. Update Lines
    line_raw.set_data(times, raw_data)
    line_wl.set_data(times, wl_data)
    line_thresh.set_data(times, thresh_data)
    line_counter.set_data(times, counter_data)

    # 3. Calculate 10-second sliding window
    current_time = times[-1]
    min_x = max(0, current_time - WINDOW_SIZE)
    max_x = max(WINDOW_SIZE, current_time)

    # We only need to set xlim on ax_raw because ax_wl and ax_counter share it
    ax_raw.set_xlim(min_x, max_x)

    # Let the WL/Threshold plot dynamically adjust its Y-axis
    ax_wl.relim()
    ax_wl.autoscale_view(scalex=False, scaley=True)

    return (
        line_raw,
        line_wl,
        line_thresh,
        line_counter,
        light_det,
        light_disc,
        light_tout,
    )


def on_close(event):
    global is_running
    is_running = False


fig.canvas.mpl_connect("close_event", on_close)

# Run animation at 20 FPS (50ms)
ani = FuncAnimation(
    fig, update_dashboard, blit=False, interval=50, cache_frame_data=False
)

plt.tight_layout()
plt.show()

data_thread.join()

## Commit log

2025-12-08 Uploading data with new names.
    [labeled_data.csv]
2025-12-08 Adding test and training data.
    [test_rand_01.csv, test_rand_02.csv, test_rand_03.csv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]
2025-12-08 Calculation results.
    [evaluation_from_training.csv, trained_thresholds.csv]
2025-12-08 Moved everything regarding Python into the new software folder.
    [evaluation_from_training.csv, labeled_data.csv, test_rand_01.csv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]
2025-12-11 Add all CAD files regarding the servo pullys
    [Pulley_Bottom.stl, Pulley_Bottom_V2.stl, Pulley_Bottom_V3.stl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]
2025-12-11 Move files in a single folder
    [Pulley_Bottom.stl, Pulley_Bottom_V2.stl, Pulley_Bottom_V3.stl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]
2025-12-11 Calibrator tests for the 3D printer
    [Calibrator.stl, Z-Offest Test.stl]
2025-12-11 Move files into the right folder
    [Calibrator.stl, Z-Offest Test.stl]
2025-12-11 Files for the custom stand of the InMoov arm
    [Arduino Holder Remix.stl, Arduino Pin v1.f3d, Arduino_Holder v1.stl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]
2025-12-23 Files of the finger starter kit
    [FingerIndexV4.stl, FingerTesterV2.stl, RobRingV2.stl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]
2025-12-23 Moved finger starter kit files into the right folder
    [FingerIndexV4.stl, FingerTesterV2.stl, RobRingV2.stl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]
2025-12-23 Files of the right forearm
    [RobCableBackV3.stl, RobCableFrontV3.stl, RobCableFrontV3_TeflonTube.f3d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]
2025-12-23 Moved forearm and servo bed files into the right folder
    [RobCableBackV3.stl, RobCableFrontV3.stl, RobCableFrontV3_TeflonTube.f3d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]
2025-12-23 Add files of the right hand
    [Auriculaire3.stl, Bolt_entretoise7.stl, Index3.stl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]
2025-12-23 Moved all files of the right hand into the correct folder
    [Auriculaire3.stl, Bolt_entretoise7.stl, Index3.stl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]
2025-12-23 Add the files of the rotation wrist
    [CableHolderWristV5.stl, RotaWrist1V4.stl, RotaWrist2V3.stl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]
2025-12-23 Moved all files of the rotation wrist into the correct folder
    [CableHolderWristV5.stl, RotaWrist1V4.stl, RotaWrist2V3.stl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]
2025-12-23 Created the folder for the remixed InMoov parts and added the servo pulleys into the correct folder
    [Pulley_Bottom.stl, Pulley_Bottom_V2.stl, Pulley_Bottom_V3.stl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]
2025-12-23 Moved the files into the right folder and removed all files unneccesary to the project
    [ForearmSketchUp.skp, LH_Forearm_Part1.stl, LH_Forearm_Part2.stl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]
2026-02-18 Arduino Filter Comparison
2026-02-18 Changing wrong file name
    [Feature_Comparison.ino]
2026-02-23 Removing the stl files and other sub-files not needed for further development. Last update of the custom stand not yet printed
    [Arduino Holder Remix.stl, Arduino Pin v1.f3d, Arduino_Holder v1.stl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]
